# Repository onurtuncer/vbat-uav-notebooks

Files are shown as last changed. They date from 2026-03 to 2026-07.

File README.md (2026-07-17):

# Electric V-BAT-Like Tail-Sitter (EDF) – Conceptual Design Study






**📖 Documentation:** rendered design notebooks are published at
**<https://onurtuncer.github.io/vbat-uav-notebooks/>**

<p align="center">
  <a href="https://onurtuncer.github.io/vbat-uav-notebooks/viewer.html">
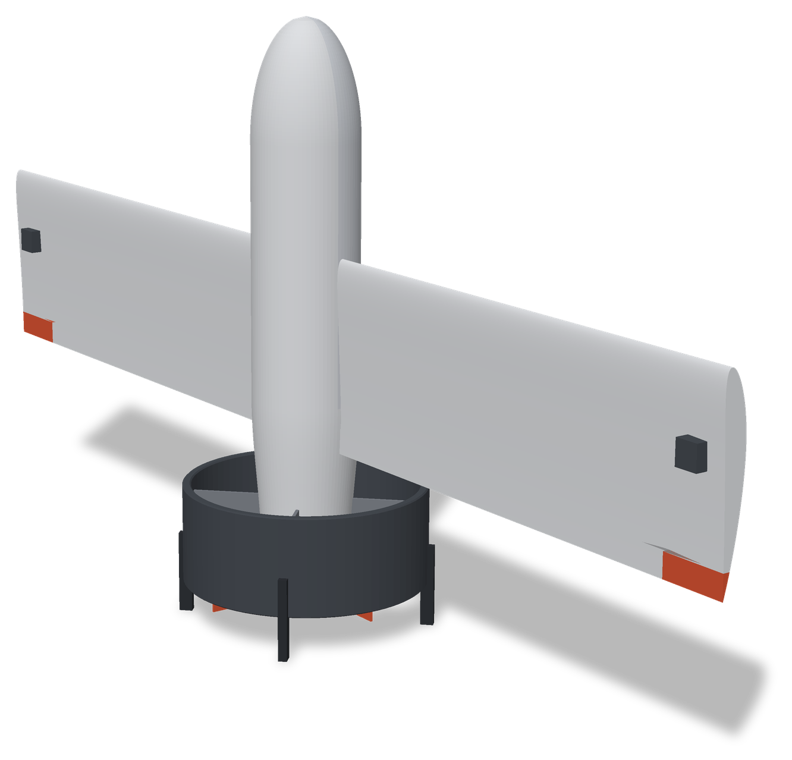
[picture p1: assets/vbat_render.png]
Rendered CAD model of the tail-sitter standing on its landing legs, nose up
    
  </a>
  <br/>
  <em>The current design point, rendered from the CadQuery solid model the
  pipeline exports on every run — click the image for the
  <a href="https://onurtuncer.github.io/vbat-uav-notebooks/viewer.html">interactive 3D viewer</a>
  (orbit, exploded view).
  Regenerate with <code>python scripts/render_readme_cad.py</code> after a design change.</em>
</p>

This repository contains a **first-principles conceptual sizing study** for a **small electric tail-sitter VTOL UAV** inspired by the *very early electric ancestors* of the V-BAT concept.

The focus is **not** on a production UAV, but on:
- architectural feasibility,
- mass / power / energy closure,
- and understanding design trade-offs at the **technology-demonstrator level**.

The code is intentionally simple, transparent, and extensible.

---

## 1. Problem Definition

### Objective
Design a **small electric ducted-fan tail-sitter UAV** capable of:

- **True VTOL** (vertical takeoff and landing)
- **Short forward flight** after transition
- Carrying **0.5 kg of payload**
- Using **electric propulsion only**
- Using **first-order physics models** suitable for early design

This mirrors the *earliest feasibility phase* of tail-sitter concepts before scaling to fuel engines, endurance optimization, or operational payloads.

---

### Design Philosophy
This study intentionally:
- avoids CFD or high-fidelity tools,
- avoids vendor-specific components,
- emphasizes **physics-based intuition**,
- and keeps all assumptions explicit.

The goal is to answer:

> *“Is this architecture feasible at this scale, and where are the dominant penalties?”*

---

## 2. Vehicle Concept (High Level)

- **Configuration:** Tail-sitter VTOL
- **Propulsor:** Electric ducted fan (EDF)
- **Wing:** Fixed wing for forward flight
- **Takeoff / Landing:** Vertical, tail-down
- **Primary regime:** Hover → transition → short cruise

This corresponds to the **electric technology demonstrators** typically built *before* SBIR Phase I funding.

---

## 3. Assumed Mission Profile

The baseline mission used for sizing is:

| Segment | Description |
|---|---|
| Hover | 120 s total (takeoff, landing, margin) |
| Cruise | 1680 s forward flight (~33.6 km at cruise speed) |
| Cruise speed | 20 m/s (~72 km/h) |
| Energy reserve | 20% |

All mission parameters are **editable** in [`config/mission.yaml`](config/mission.yaml).

---

## 4. Payload & Mass Target

- **Payload:** 0.5 kg  
  (sensor + avionics representative of early demonstrators)

Initial mass breakdown assumptions:
- avionics
- structure
- EDF + motor + ESC
- battery
- miscellaneous margin

Mass closure is solved iteratively.

---

## 5. Modeling Approach

### Hover
Hover power is estimated using **momentum (actuator disk) theory**:

$$
P_{ideal} = \frac{T^{3/2}}{\sqrt{2 \rho A}}
$$

with an overall hover efficiency applied to account for:
- duct losses,
- motor/ESC losses,
- non-ideal inflow.

A minimum **thrust-to-weight ratio** is enforced for control margin.

---

### Cruise
Cruise power is estimated using a simple **L/D model**:

$$
P = \frac{W}{(L/D)} \cdot V
$$

This is appropriate for:
- early conceptual sizing,
- rapid trade studies,
- understanding sensitivity to aerodynamic quality.

---

### Battery
Battery mass is computed from:
- total mission energy,
- pack-level specific energy,
- usable fraction (reserve).

No thermal or current limits are enforced at this stage.

---

## 6. Repository Structure

```
config/                  Design inputs (mission, aero, battery, rotor, ... as YAML)
src/conceptual_design/   All physics models (sizing, power, mass closure)
src/conceptual_design/cad/  CadQuery solid-model generators
notebooks/               Design notebooks (import from src/, write to out/)
out/                     Generated design outputs (YAML, STEP/STL, plots)
docs/                    Theory notes (hover, cruise, battery models)
tests/                   Unit tests for the physics modules (pytest)
cfd/                     OpenFOAM cases (vehicle, prop, vanes) + post-processing
printprep/               3D-print preparation scripts
```

### Design rule
- **All physics lives in `.py` files**
- **The notebook only imports and experiments**

This mirrors best practice in research and aerospace R&D codebases.

---

## 7. Requirements

### Python
- Python **3.10+**

### Python packages
Install the package in editable mode with the notebook and CAD extras:

```bash
pip install -e ".[cad,notebooks]"
```

CadQuery (`cad` extra) is only needed for the solid-model notebook
(`vehicle_solid_model.ipynb`); everything else runs on the plain
scientific stack (`pip install -e .`).

### OpenFOAM (optional)
The `Allrun.*` scripts under [`cfd/`](cfd/) run external-aero RANS
analyses of the generated geometry. They require a sourced
**OpenFOAM.com (v2306+)** environment and are independent of the Python
toolchain. See [`cfd/README.md`](cfd/README.md).

## 8. How to Run

Open a terminal in the repository root and launch Jupyter:

```bash
jupyter lab
```

Run the notebooks top-to-bottom **in this order** (each one writes YAML
handoff files to `out/` that the next one reads):

1. `notebooks/vbat_conceptual_design.ipynb` — mission sizing & mass closure
2. `notebooks/wing_design.ipynb` — airfoil selection & wing design
3. `notebooks/control_vane_design.ipynb` — control vane sizing
4. `notebooks/fuselage_design.ipynb` — fuselage layout & drag trade (reads the vane results)
5. `notebooks/vehicle_solid_model.ipynb` — full-vehicle CAD (STEP/STL export)

Adjust parameters in `config/*.yaml` and re-run to explore trade-offs.

### Tests

```bash
pip install -e ".[dev]"
pytest
```

### Versioning & releases

The package version derives from **git tags** via `setuptools-scm`
(`v0.1.0` → `0.1.0`; commits after a tag get a `.devN` suffix — never
edit a version number by hand). Tagging a release freezes the design:

```bash
git tag v0.2.0 && git push --tags
```

CI then re-runs the whole design pipeline and attaches the design
snapshot (design-point YAMLs, STEP/STL geometry, rendered notebooks) to
the [GitHub Release](https://github.com/onurtuncer/vbat-uav-notebooks/releases).
Suggested convention: bump **minor** for a new design point or analysis
capability, **patch** for corrections that do not move the design.

## 9. Intended Extensions

This framework is designed to grow. Natural next steps include:

- wing sizing & stall constraints
- EDF continuous vs burst power limits
- disk loading vs noise trade-offs
- thermal limits (motor & ESC)
- parametric sweeps and Pareto fronts
- hybrid-electric or fuel-based scaling

Each extension should live in new modules

## 10. Scope & Limitations

This study:

❌ is not a flight-ready design

❌ ignores structural stress analysis

❌ ignores control law implementation

❌ ignores certification or safety

It is appropriate for:

- concept feasibility
- academic exploration
- architecture comparison

## 11. Motivation

Tail-sitter VTOL aircraft occupy a unique design space where:

- hover power dominates,
- transition dynamics are critical,
- and endurance scaling is non-trivial.

This repository exists to make those trade-offs explicit and quantitative.

## 12. License

Please see LICENSE file. Open for research and educational use.
(No warranty, no fitness for flight.)

## Author Notes

This project intentionally mirrors how early electric V-BAT-like demonstrators would have been sized before fuel engines, autonomy stacks, or other payloads were introduced.

## 👤 Author

**Prof.Dr. Onur Tuncer**  
Aerospace Engineer, Researcher & C++ Systems Developer  
Email: **onur.tuncer@itu.edu.tr**

<p align="left">
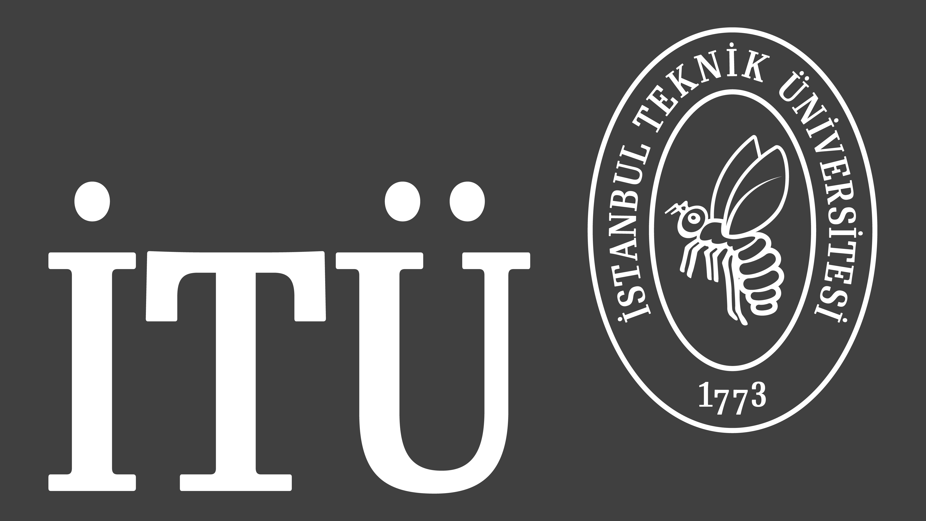
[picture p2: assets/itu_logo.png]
Istanbul Technical University
  
</p>

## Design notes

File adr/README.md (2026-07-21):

# Architecture Decision Records

This folder holds Architecture Decision Records (ADRs) — short documents
capturing an architecturally significant decision, its context, and its
consequences. New ADRs are added when an architectural decision is made;
existing ADRs are never rewritten (a superseding decision gets a new ADR
that marks the old one `Superseded`).

Format: one file per decision, `NNNN-kebab-title.md`, each with
**Status / Context / Decision / Consequences**.

| ADR | Title | Status |
|-----|---|---|
| [0001](0001-one-way-design-pipeline.md) | One-way design pipeline (config → src → notebooks → out → cfd) | Accepted |
| [0002](0002-all-physics-in-src-no-magic-numbers.md) | All physics in `src/`; no magic numbers in Python | Accepted |
| [0003](0003-cots-edf-derived-disk-loading.md) | COTS 195 mm EDF; disk loading derived, not configured | Accepted |
| [0004](0004-dual-roll-control-vanes-and-ailerons.md) | Dual roll control: jet vanes (hover) + ailerons (cruise) | Accepted |
| [0005](0005-mass-fraction-carve-out-with-traceability.md) | Mass-fraction carve-out with traceability and a guard | Accepted |
| [0006](0006-tag-driven-versioning-and-ci-tiers.md) | Tag-driven versioning and tiered CI | Accepted |
| [0007](0007-vibration-isolation.md) | Soft-mount the FC/IMU and payload against EDF imbalance | Accepted |
| [0008](0008-segmented-fdm-construction.md) | Segmented-FDM construction as the baseline airframe | Amended by 0010 |
| [0009](0009-thermal-paths-as-structure.md) | Thermal paths as structure (ESC cold-plate + vented battery bay) | Accepted |
| [0010](0010-semi-monocoque-clamshell.md) | Semi-monocoque clamshell fuselage (external review) | Accepted |
| [0011](0011-px4-flight-validation-before-custom-fc.md) | Fly on PX4 + COTS Pixhawk before a custom flight controller | Accepted |
| [0012](0012-post-freeze-as-selected-resolve.md) | Post-freeze as-selected re-solve as new downstream notebooks | Accepted |
| [0013](0013-thin-notebooks-code-in-src.md) | Thin notebooks: physics/plots/reports code lives in src | Accepted |
| [0014](0014-battery-pack-transient-thermal-check.md) | Battery pack mission-transient thermal check | Accepted |
| [0015](0015-naca-4412-airfoil-reselection.md) | Airfoil re-selection: NACA 2412 → NACA 4412 | Accepted |
| [0016](0016-aeolion-geometry-handoff.md) | Versioned JSON plus STEP for the Aeolion handoff | Accepted |
| [0017](0017-prop-blade-clark-y-section-and-rotation-sense.md) | Propeller blade section (Clark Y) and rotation sense | Accepted |
| [0018](0018-aeolion-handoff-own-notebook.md) | Aeolion handoff as its own pipeline notebook stage | Accepted |

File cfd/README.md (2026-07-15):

# CFD Cases (OpenFOAM)

RANS (simpleFoam, k-omega SST) cases characterizing the V-BAT tail-sitter,
using geometry and reference quantities produced by the notebooks
(`out/cad/`, `out/fuselage.yaml`, `out/control_vanes.yaml`,
`config/mission.yaml`). Tested against OpenFOAM.com v2306+.

| Directory | Purpose |
|---|---|
| `vehicle/` | Full-vehicle external aero: mesh from `out/cad/stl/vbat_fused.stl`, single-AoA runs, and AoA polar sweeps |
| `prop/` | Ducted-fan propulsion map via actuator disk (parametric duct + centerbody geometry, thrust x velocity sweep) |
| `vanes/` | Control-vane characterization: flat-plate vane in the duct jet, deflection sweep |
| `postprocess/` | Exporters from `postProcessing/` force histories to DAVE-ML (`foam2dml.py` for the vehicle polar, `foam2dml_prop.py` for prop/vane sweeps) |

## Run order

```bash
# Full-vehicle aero polar (requires repo STL/STEP under out/cad/)
cd vehicle
./Allrun.mesh                      # geometry -> snappyHexMesh -> checkMesh
./Allrun.case -a 0 -V 20 -n 8 -s   # single AoA, or:
./Allrun.polar -n 8 -V 20 -- -4 -2 0 2 4 6 8 10 12
python3 ../postprocess/foam2dml.py --polar-dir polar --out vbat_aero_cfd.dml --plot

# Propulsion map (duct/hub dims read from out/fuselage.yaml via make_geom.py)
cd prop
./Allrun.prop -n 8
python3 ../postprocess/foam2dml_prop.py --prop-dir sweep

# Vane sweep
cd vanes
./Allrun.vanes -n 8
python3 ../postprocess/foam2dml_prop.py --vane-dir sweep
```

Run artifacts (meshes, `log/`, `processor*/`, `postProcessing/`, sweep
directories) are generated in place and gitignored; only the Allrun
scripts, `system/` dictionaries, and Python tooling are tracked.

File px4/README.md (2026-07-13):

# px4/ — PX4 flight-stack configuration (ADR-0011)

Pipeline consumer, downstream of `out/` — the same role `cfd/` plays:

```
config/*.yaml -> src/ -> notebooks/ -> out/ -> px4/   (this directory)
                                        |
                                        v
                              cfd/ sweep results
                                        |
                                        v
                     out/daveml/*.dml  (generated, AIAA S-119)
                                        |
                                        v
                    Aetherion 6-DoF plant (separate repo)
                                        |
                          simulator-MAVLink lockstep (TCP 4560)
                                        |
                                        v
                                   PX4 SITL
```

The SITL physics plant is **Aetherion** (github.com/onurtuncer/Aetherion)
consuming DAVE-ML models generated from this repo's CFD results — the
built-in Gazebo aero is not trusted for this vehicle (no jet wash, no
post-stall, no power-on effects; see ADR-0011). The DAVE-ML contract
lives in [sitl/daveml_spec.md](sitl/daveml_spec.md).

Everything numeric in here is **copied from `config/` or `out/`
handoffs** and carries a provenance comment naming the source (the
`Allrun.case` discipline). An intentional design change must update
these values in the same commit. A generator script from `out/*.yaml`
is the planned follow-up once the file set stabilises.

Design point (ADR-0003 prop-in-duct amendment, 2026-07-12): MTOW
2.302 kg, hover ~652 W / 29.4 N (1.3 T/W), 6S 3.50 Ah, cruise 20 m/s.

## Layout

| Path | What it is |
|---|---|
| `airframes/22100_vbat_tailsitter` | Hardware airframe file (custom start script for the PX4 ROMFS, `init.d/airframes` style). Source of truth for all tunable params. |
| `sitl/daveml_spec.md` | Contract for the CFD-derived DAVE-ML model set (`out/daveml/*.dml`) consumed by Aetherion — grids, frames, check-cases, validation gates. |
| `sitl/airframes/4801_gz_vbat_tailsitter` | SITL (Gazebo `gz`) airframe file, `init.d-posix` style. Param values are kept in sync with the hardware file by hand. |
| `sitl/models/vbat_tailsitter/` | Gazebo model (`model.sdf` + `model.config`) — **integration smoke checks and visualisation only**, not a trusted plant. Inertia from `out/mass_properties.yaml`, geometry from `out/fuselage.yaml` / `out/control_vanes.yaml`. |

The PX4 lockstep bridge and sensor models live in the Aetherion
repository; this repo only produces the `.dml` inputs and the PX4
parameter set.

## Vehicle → PX4 mapping

- **Airframe type:** VTOL Tailsitter (`CA_AIRFRAME = 4`, `VT_TYPE = 0`),
  dynamic control allocation (PX4 ≥ v1.14).
- **Motor:** single ducted 3-blade prop, `CA_ROTOR_COUNT = 1`, thrust along body +x
  (out the nose, FRD).
- **Jet vanes:** four custom control surfaces (CS0–CS3 = T/B/L/R). Their
  roll/pitch/yaw torque entries transcribe the mixing matrix in
  `out/control_vanes.yaml` (rows T,B,L,R × cols pitch,yaw,roll).
- **Ailerons:** CS4/CS5 as left/right aileron — the cruise-phase roll
  effector (ADR-0004); jet vanes remain available as roll backup.
- **Outputs:** 1 ESC (DShot preferred — RPM telemetry feeds the dynamic
  notch filter) + 6 servos.

## Known limitations / open work

1. **Param names are drafted against PX4 v1.15 docs and not yet
   validated against a pinned release.** Validate before first SITL run;
   then add cross-checks to `tests/test_design_outputs.py`.
2. **The trusted SITL plant does not exist yet.** Its pieces are named
   work items (ADR-0011): the parametric CFD sweep runner and the
   DAVE-ML generator in this repo, the PX4 lockstep bridge + sensor
   models in Aetherion. The Gazebo model remains usable for PX4-side
   plumbing checks (actuator mapping, mode logic, parameter sanity) but
   its vane aero blocks are physically meaningless placeholders — the
   plugins see the freestream, not the rotor jet — so no flight-dynamics
   conclusion may be drawn from it.
3. **Vane effectiveness ∝ thrust** is not modelled by PX4's allocator —
   expect apparent gain variation through transition; tune with the
   ailerons carrying cruise roll as designed.
4. Servo directions/signs must be verified on the bench against the
   FRD axis convention before flight — the matrix here fixes relative
   signs only.

## Usage

**SITL against Aetherion (the trusted path, once the bridge exists):**
build the Aetherion PX4 bridge pointing at `out/daveml/`, start PX4 with
no built-in simulator (`make px4_sitl none_vbat_tailsitter` — external
sim connects on TCP 4560 in lockstep), then launch the bridge. Exact
invocation is defined by the bridge in the Aetherion repo.

**Gazebo smoke run** (PX4-side plumbing checks only — not flight
dynamics; Linux, PX4-Autopilot checkout, Gazebo Harmonic):

```sh
# make the model and airframe visible to the PX4 build
export GZ_SIM_RESOURCE_PATH=$GZ_SIM_RESOURCE_PATH:/path/to/vbat-uav-notebooks/px4/sitl/models
cp px4/sitl/airframes/4801_gz_vbat_tailsitter \
   PX4-Autopilot/ROMFS/px4fmu_common/init.d-posix/airframes/
# add it to that directory's CMakeLists.txt, then:
make px4_sitl gz_vbat_tailsitter
```

**Hardware:** copy `airframes/22100_vbat_tailsitter` into
`ROMFS/px4fmu_common/init.d/airframes/` of a PX4 source build (register
it in the CMakeLists), or replay the same `param set-default` lines as a
QGroundControl parameter import after selecting a generic VTOL
tailsitter airframe.

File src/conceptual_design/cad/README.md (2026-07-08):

# CAD Assets – VBAT Conceptual Design

This directory contains all CAD geometry related to the electric
tail-sitter (VBAT-style) UAV conceptual design.

Geometry is generated programmatically using **CadQuery**
(built on OpenCascade / OCCT).

---

## Philosophy

All primary geometry should be:

- Parametric
- Reproducible
- Script-generated when possible
- Version-controlled at the source level

The CAD models are treated as **derived artifacts** from the Python
conceptual design codebase.

---

## Directory Structure

This package contains the geometry **generators**:

cad/
├─ wing_profile.py      # NACA sections (math from airfoil_selection.py)
├─ fuselage_body.py     # body of revolution (meridian from fuselage_design.py)
├─ vehicle_assembly.py  # full vehicle: fuselage, wing, duct, vanes, legs
└─ README.md

Generated artifacts are **derived outputs** and live under `out/` (gitignored):

out/cad/
├─ step/ # STEP solids for CAD exchange (assembly + fused)
└─ stl/  # Mesh exports for visualization or 3D printing

## Axis Convention (Aetherion-compatible)

Body frame **FRD**: x forward (out the nose), y right, z down.
Origin at the nose tip; the EDF exhaust points in -x.
World frame is NED.

## Units

- Public function arguments and all `out/*.yaml` handoffs: **meters (m)**
- OCCT geometry and STEP/STL exports: **millimetres (mm)** (CAD convention);
  scaling happens inside the modules.

---

## Generation Workflow

CAD geometry is generated from Python using:

Typical workflow:

1. Adjust parameters in `config/*.yaml`.
2. Re-run the upstream notebooks (sizing -> airfoil -> vanes -> fuselage).
3. Run `notebooks/vehicle_solid_model.ipynb` to regenerate
   `out/cad/step/` and `out/cad/stl/`.

Example (full vehicle from the YAML handoffs):

```python
import yaml
from conceptual_design.cad.vehicle_assembly import build_vehicle, export_vehicle

fus   = yaml.safe_load(open("out/fuselage.yaml"))
vanes = yaml.safe_load(open("out/control_vanes.yaml"))
asm, fused = build_vehicle(fus, vanes, b_wing_m=1.002,
                           chord_wing_m=0.167, wing_designation="NACA 2412")
export_vehicle(asm, fused, "out/cad")
```

## Planned Geometry Modules

- Wing (lofted root–tip sections)
- Spar cutouts
- Rib generation
- Fuselage parametric body
- Duct / fan housing
- Mounting structures

## Long-Term Goal

CAD is tightly coupled to the conceptual design:

- Mission → mass → wing loading → chord/span → geometry

Geometry should be derivable from YAML configuration

This ensures:

-Design traceability
-Repeatability
-Parametric trade studies

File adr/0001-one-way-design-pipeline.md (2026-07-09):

# 1. One-way design pipeline (config → src → notebooks → out → cfd)

Status: Accepted

## Context

A conceptual design study couples many disciplines (mission sizing,
aerodynamics, structures, CAD, CFD, electrical). Left unstructured, inputs,
physics, and orchestration bleed into each other: constants get hard-coded in
notebooks, one notebook reaches into another's internals, and reproducing a
design point becomes guesswork. We need a data-flow discipline that makes the
design point reconstructible and every artifact traceable to its inputs.

## Decision

Data flows one way through five stages:

```
config/*.yaml  ->  src/conceptual_design/  ->  notebooks/  ->  out/  ->  cfd/
(inputs)           (ALL physics)               (orchestrate)   (handoffs)  (consumers)
```

- `config/*.yaml` holds every input parameter.
- `src/` holds all physics as importable modules.
- Notebooks only set parameters, call modules, interpret results, and write
  YAML/CSV **handoffs** to `out/`.
- Each notebook reads only the `out/` handoffs of the notebooks before it and
  re-runs `run_sizing_loop` from `config/` to reconstruct the same design
  point. Notebook execution order is therefore load-bearing.
- CFD and other consumers read `out/` but never feed back into it.

## Consequences

- The design point is reconstructible from `config/` alone; `out/` is a
  cache, regenerated by re-running the notebooks in order.
- Changing the sizing API means updating every notebook's `run_sizing_loop`
  call site (NB2–NB8) — a known, enumerated cost.
- Cross-notebook coupling is explicit and append-only (via `out/` files),
  which is what lets CI regenerate and regression-check the whole chain.
- No backward edges: a downstream discovery (e.g. a CG shift found in
  `mass_properties`) is fed back by changing `config/`/`src/` and re-running,
  not by editing an upstream `out/` file in place.

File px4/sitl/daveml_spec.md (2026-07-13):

# DAVE-ML model database spec (draft, ADR-0011)

Contract between this repo's CFD results and the Aetherion 6-DoF plant
used for PX4 SITL. Producer: a generator script in this repo (follow-up
work item) writing `out/daveml/*.dml` from CFD sweep results + existing
`out/` handoffs. Consumer: Aetherion's `Serialization/DAVEML` readers
(`DAVEMLAeroModel` via the generic `evaluateRaw` map interface,
`LoadInertiaFromDAVEML`, a prop-style wrapper).

Conformance: **DAVE-ML 2.0 (AIAA S-119)**, gridded tables + MathML,
embedded check-cases mandatory (Aetherion's F-16 files are the style
reference). Units: **SI native** (m, m/s, N, N·m, deg for angles,
matching the F-16 file convention of degrees for aero angles).
NOTE: Aetherion's `getValueSI` assumes imperial native units (slug, ft);
verify its readers pass SI-native units through unchanged — flagged as
an Aetherion-side check.

## Frames, references, provenance

- Body **FRD**, x out the nose (project-wide convention). Moments about
  the CG; forces/moments and their coefficient forms use the same signs
  as the F-16 reference set (`cx` +fwd, `cz` +down, `cm` +nose-up, …).
- Reference quantities pinned to `cfd/vehicle/Allrun.case` (and the
  regression pins in `tests/test_design_outputs.py`):
  `S_ref = 0.18925 m²`, `c_ref = 0.17760 m` (MAC = chord, rectangular
  wing), `b_ref = 1.0655 m`, moment centre `(-0.23841, 0, 0)` = CG.
- Every file carries the standard AUTO-GENERATED provenance header
  (source case, mesh/solver settings hash, generation date) and is
  re-generated — never hand-edited — when the design point moves.

## The hover-normalisation split (structural decision)

At hover `q_∞ → 0`, so `C = F/(q_∞ S)` is singular exactly where a
tailsitter lives. The database is therefore split:

| File | Form | Valid regime |
|---|---|---|
| `vbat_aero.dml` | coefficients (power-off airframe) | V ≥ ~5 m/s |
| `vbat_prop.dml` | **dimensional** N / N·m vs throttle state | all speeds |
| `vbat_vanes.dml` | **dimensional** N / N·m vs deflection + jet state | all speeds |
| `vbat_inertia.dml` | constants | — |

Total loads = airframe coefficients (faded in with airspeed) +
prop/duct + vane increments. Aetherion composes the superposition; the
fade law is defined here (breakpointed on airspeed), not hardcoded there.

## vbat_aero.dml — power-off airframe

Inputs: `alpha` [deg], `beta` [deg], `vt` [m/s], `p`,`q`,`r` [rad/s],
`da_l`,`da_r` [deg] (aileron deflections).
Outputs: `cx cy cz cl cm cn`.

Draft breakpoint grid (transition corridor gets the density):

- `alpha`: −180…180; 2.5° steps in [−10, +30], 5° in [30, 90], 15°
  beyond (tail-sitter passes through 90° — the post-stall band is the
  point of doing this at all)
- `beta`: 0, ±5, ±10, ±20 (symmetry exploited in generation)
- `vt`: 5, 10, 16, 20, 26 m/s (Re sensitivity check decides whether
  the vt axis survives or collapses to one Re)
- aileron: 0, ±10, ±20° (increments; rate derivatives `p,q,r` are NOT
  CFD-derived initially — first fill from analytic/DATCOM estimates,
  flagged `estimated` in the varDef description, replaced if forced
  oscillation or system-ID data arrives)

## vbat_prop.dml — EDF + duct, power-on

Inputs: `throttle` [0–1] (or `rpm`), `vt` [m/s], `alpha` [deg].
Outputs: `fx_N fy_N fz_N mx_Nm my_Nm mz_Nm` **plus `q_jet_Pa`** (feeds
the vane model — the F-16 prop file has no such coupling; this one must).
Must capture duct normal force and pitching moment at incidence
(dominant tailsitter transition effect) — this is the actuator-disk CFD
sweep, power-on minus power-off.

Draft grid: throttle {idle, cruise ≈ 0.15, hover 0.61, max 1.0} ×
vt {0, 5, 10, 16, 20, 26} × alpha {0, 15, 30, 60, 90}.
Static check-cases: hover 30.3 N at throttle 0.61; `T_max_N` 50 at 1.0
(config/rotor.yaml); `q_jet` 780.3 Pa at hover (out/control_vanes.yaml).

## vbat_vanes.dml — jet vane increments

Inputs: `dv_t dv_b dv_l dv_r` [deg, ±20 hard stop], `q_jet_Pa` (from the
prop model), `vt`, `alpha`.
Outputs: incremental `fx_N … mz_Nm` about the CG.

Draft grid: deflection −20…+20 in 5° steps (one vane swept, others
zero; cross-coupling spot-checked), q_jet {cruise, 0.5·hover, hover,
max}. First-issue tables may come from the analytic model in
`src/conceptual_design` (provenance-flagged), replaced by CFD
(resolved-vane or momentum-source runs) sweep by sweep — the .dml
interface stays fixed while fidelity improves underneath.
Check-case: 10° single vane at hover q_jet → 0.719 N
(out/control_vanes.yaml) for the analytic issue; re-pinned when CFD
replaces it.

## vbat_inertia.dml

Straight transcription of `out/mass_properties.yaml`: mass 2.37626 kg,
Ixx 0.022453, Iyy 0.041776, Izz 0.054148 kg·m² (products zero), CG
(-0.23841, 0, 0). Battery-tray CG travel (±0.025 m) exposed as the one
input variable, mirroring the F-16 file's `CG_PCT_MAC` pattern.

## Validation gates (Aetherion side)

1. S-119 embedded check-cases pass in Aetherion's Catch2 suite.
2. Static hover trim: thrust = weight at throttle ≈ 0.61, vanes ≈ 0.
3. Cruise trim at 20 m/s reproduces CL ≈ 0.50 and L/D consistent with
   `out/airfoil.yaml` (13.2 wing-only, less airframe drag).
4. Vane authority at hover reproduces the `ddot_*` design values of
   `out/control_vanes.yaml` before any PX4 gain tuning is attempted.

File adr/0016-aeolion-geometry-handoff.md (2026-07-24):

# ADR-0016: Schema-pinned parametric JSON for the Aeolion geometry handoff

Status: Accepted (2026-07-19; supersedes the earlier ad-hoc JSON draft)

## Context

Aeolion (companion VLM/BEMT repo) closes an adjoint optimization loop
over the VBAT geometry. It needs a differentiable, fixed-topology
parametric description — not the watertight STEP solid, whose booleans
and tessellation are nondifferentiable. The Aeolion side pinned the
contract as a JSON Schema (2020-12, `additionalProperties: false`).

## Decision

- The contract is `schemas/vbat-aeolion-geometry-handoff.schema.json`
  (schema_version **1.0.0**), stored verbatim in this repo and
  validated by `tests/test_aeolion_handoff.py` (jsonschema, dev extra).
- NB8 (`vehicle_solid_model`) exports `out/cad/aeolion_geometry.json`
  beside the STEP files (same execution ⇒ same design point), built by
  `src/conceptual_design/aeolion_handoff.py`.
- **Frame/units**: `aetherion_body_frd`, metres, degrees — identical to
  the repo axis convention, so there is no transform seam to
  differentiate through.
- **Fixed design-vector structure**: station count, CST order, BEMT
  station count, and mesh topology come from `config/aeolion.yaml` and
  are structural constants of the optimization, not design variables.
  Changing them is an outer-loop remeshing event (deliberate commit).
- **Airfoil sections are Kulfan CST fits** (class function
  x^0.5·(1−x)^1.0, least squares) of the NB2-selected section. The
  schema has no trailing-edge-thickness term, so each surface is fitted
  after removing the linear TE ramp — the handoff carries the sharp-TE
  aerodynamic equivalent (what a VLM camber surface consumes). Fit RMS
  is test-guarded at < 1e-3 c.
- **BEMT blade stations sample the same chord/twist law as the CAD
  rotor** (`prop_geometry.PropGeometry`, moved out of `cad/` so it
  imports without CadQuery): r/R from the hub collar to the tip, exact
  constant-geometric-pitch twist, `reference_rpm` from the NB5 hover
  1/rev. One law, three consumers (CAD, BEMT, vibration-forcing).
- **Controls**: the aileron and the four jet vanes are emitted. Vane
  entries reuse the schema's control-surface shape for the duct jet:
  eta is the duct-exit radius fraction (hub collar → duct wall), the
  hinge axes are the radial vane directions (CAD angle convention:
  about +x, 0° = +z), and `chord_fraction: 1.0` marks the all-moving
  plate rotating about its `hinge_xc` line. The vane CFD → DAVE-ML
  path still characterizes the jet-wash aerodynamics; carrying the
  geometry here lets Aeolion model the jet directly.
- **Duct block (schema 1.8.0, 2026-07-24)**: the EDF shroud rides in
  the contract explicitly — a new top-level `duct` block with
  `inner_diameter` / `outer_diameter` / `chord` and
  `placement.center`, the SAME parameterisation the CAD duct solid is
  built from (`out/fuselage.yaml` `D_duct_inner_m` / `D_duct_outer_m`
  / `duct_chord_m` and the layout duct station): an annulus of
  revolution about the body x-axis, mid-chord centre at x = −station
  (same convention as `body`), inlet face forward at
  `center.x + chord/2`. Before this the duct existed in the contract
  only by implication — the vane entries' eta is measured on the
  duct-EXIT radius and BEMT models a prop-in-duct, yet no duct
  geometry or position was stated anywhere, so a duct-aware consumer
  had nothing to place against `body` (and the duct legitimately
  overhangs the tail base, so guessing from the body extent gets it
  wrong). The bore carries the rotor tip clearance — new exporter
  guard `rotor_D < D_duct_inner < D_duct_outer`, plus exactly one
  `duct` item required in the fuselage layout. **Required from 1.8.0
  onward**, same version-conditional `if`/`then` discipline as
  `planform.placement` and `moment_reference_point`; 1.0.0–1.7.0
  documents remain structurally valid without it.
- **Moment reference point (schema 1.6.0, 2026-07-21, from an Aeolion
  solver report)**: a new top-level `moment_reference_point` {x, y,
  z} carries the vehicle CG, in the SAME body-frame convention and
  from the SAME source (`out/fuselage.yaml` `x_CG_m`) as
  `cfd/vehicle/Allrun.case`'s `CofR` — so VLM/BEMT moments computed
  from this contract stay directly comparable to the project's CFD
  force/moment coefficients, not an arbitrary second reference.
  Without it, Cm/Cl/Cn have no stated centre and default to the
  coordinate-system origin — not physically meaningful for a body
  whose CG sits well aft of the nose. **Required from 1.6.0 onward**,
  same discipline as `planform.placement`: a version-conditional
  `if`/`then` (`schema_version` not in the pre-1.6.0 list ⇒
  `moment_reference_point` required at the document root), so
  1.0.0–1.5.0 documents remain structurally valid without it. New
  exporter guard mirrors the placement guard: `0 < x_CG_m < L_fus_m`.
- **Wing/body placement (schema 1.5.0, 2026-07-20, from an Aeolion
  solver-side bug report)**: `planform` gained a `placement.
  root_leading_edge` anchor {x, y, z} in the same body-frame
  convention `body` already uses (x = -station, 0 at the nose tip).
  Before this the planform and the body profile each implicitly
  started at the reference-frame origin, so a consumer with no other
  convention to fall back on placed the wing root at the fuselage
  nose — 22 of 384 wing control points landed inside the body of
  revolution in Aeolion's report, a boundary condition with no
  physical meaning. The anchor is `[-x_wing_LE_m, 0, 0]`: the wing
  chord datum sits on the fuselage centerline by construction (a
  through-fuselage wing on the ADR-0008 carry-through spar), not an
  incidental default. **Required from 1.5.0 onward** — unlike every
  earlier addition, this field is NOT optional for its own version,
  because the unsafe fallback (assume the origin) is exactly the bug
  being fixed; the schema enforces this with a version-conditional
  `if`/`then` (`schema_version` not in the pre-1.5.0 list ⇒
  `planform.placement` required) rather than a prose promise, so
  1.0.0–1.4.0 documents that never carried it remain structurally
  valid while every 1.5.0+ document is held to the anchor. The
  exporter also guards `0 < x_wing_LE_m < L_fus_m` so a future design
  change can't silently regress the wing outside the fuselage again.
  The natural follow-on — trimming the wing planform/lattice at the
  fuselage surface so the root load transfers to the body — is left
  to Aeolion's side now that placement exists; it needs the `body`
  radius law (already in the contract since 1.2.0) evaluated at the
  root LE station, not a new VBAT field.
- **Deflection range (schema 1.4.0, 2026-07-20)**: every
  `control_surfaces` entry carries `deflection_limits_deg` — the
  symmetric mechanical range about `hinge_axis` (`±delta_max_deg` from
  `out/aileron.yaml` / `out/control_vanes.yaml`), so a CFD/VLM
  deflection sweep never asks for an angle the physical actuator/plate
  cannot reach. Vane entries additionally carry
  `deflection_soft_limit_deg` (the flat-plate stall onset,
  `delta_stall_deg`) — informational, not a hard bound, since sweeping
  past it is a legitimate (if off-design) query.
- **Blade count (schema 1.3.0, 2026-07-20, missing field caught in
  review)**: `propulsion_bemt.n_blades` (from the same
  `prop_geometry.PropGeometry` the blade stations sample). BEMT
  solidity and thrust are per-blade quantities scaled by blade count —
  `blade_stations` alone describes one blade's chord/twist law, not
  the rotor, so the count was a load-bearing gap, not an
  optional refinement.
- **Body block (schema 1.2.0, 2026-07-19)**: the fuselage rides in the
  contract as a body of revolution — `body.stations` of {x, radius}
  sampled from the same 3-segment meridian the CAD revolve is built
  from (`fuselage_design.fuselage_radius`: elliptical nose, cylinder,
  tail cone to the hub radius), cosine-spaced nose → tail at a fixed
  count (`n_body_stations`, config/aeolion.yaml), body x = −station
  (0 at the nose tip, negative aft, consistent with
  `aetherion_body_frd`). Optional in the schema (1.0.0/1.1.0 documents
  stay valid); never bound to a lifting lattice — intended for
  slender-body/Munk trim corrections and duct-jet context. One
  meridian law, two consumers (CAD revolve, handoff).
- **Surface binding (schema 1.1.0, 2026-07-19, from the Aeolion-side
  review)**: control-surface entries carry an explicit `surface` field
  — `wing` (eta = semispan fraction of the planform) or `duct_jet` (an
  all-moving plate in the jet, eta = duct-exit radius fraction, never
  bound to a lifting-surface lattice). The field is optional so 1.0.0
  documents stay valid; when absent the binding convention is by
  `name`: `aileron`/`rudder` → `wing`, `vane` → `duct_jet`. The
  exporter always emits it. Frame conversion remains the consumer's
  explicit job at ingest (the contract states `aetherion_body_frd`
  once; a z-up VLM flips x and z — a proper rotation about y).
- **`design_id`** is `sha256:<hex>` over the canonical JSON of every
  other field: byte-stable when the design point is unchanged (clean
  regression diffs), guaranteed to move when any parameter moves —
  the adjoint-loop traceability key.

## Rationale

VLM needs a mean lifting lattice; passing span, per-station chord /
twist / sweep / dihedral, and CST sections preserves design intent and
keeps every quantity on a differentiable path. A CppAD implementation
can template geometry → residual → solve → objective on the scalar
type; JSON parsing stays outside the tape and supplies values, while
the fixed array lengths guarantee a constant tape structure.

STEP remains the exact CAD/traceability artifact, but because the
schema forbids additional properties, the STEP linkage is by
construction (same NB8 run, same `out/cad/` directory) rather than by
a field inside the JSON.

## Consequences

- Any change of field meaning requires a schema-version bump on the
  Aeolion side first; this repo follows the pinned schema file.
- The document intentionally repeats identical chord/CST data at every
  station today (rectangular untwisted wing) — that redundancy IS the
  contract for future twist/taper design variables.
- Design changes show up as a new `design_id`; CI's byte-diff of
  `out/cad/aeolion_geometry.json` doubles as a design-regression pin.

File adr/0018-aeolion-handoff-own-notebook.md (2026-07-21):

# ADR-0018: Aeolion handoff as its own pipeline notebook stage

Date: 2026-07-22
Status: Accepted

## Context

`build_aeolion_geometry`/`export_aeolion_geometry` (ADR-0016) were
called from a tail cell of `vehicle_solid_model` (NB8) because that's
where the CAD assembly and the parametric prop rotor were already
being built, and the ADR-0016 rationale explicitly framed the JSON as
sitting "beside the existing assembly and fused STEP files."

Since then the contract has grown: six schema revisions in three days
(1.0.0 → 1.7.0, ADR-0016/0017), a real design decision of its own
(the Clark Y blade section, ADR-0017), and a numerically-derived
physical fact (rotation sense) — enough surface area that it no longer
reads as an afterthought at the end of the CAD notebook.

It's also, on inspection, not actually coupled to CAD at all:
`build_aeolion_geometry`'s every input — wing span/chord from the
sizing result, `out/airfoil.yaml`, `out/control_vanes.yaml`,
`out/aileron.yaml`, `out/vibration.yaml`, `out/fuselage.yaml`,
`config/prop_geometry.yaml`, `config/airfoils/clarky.dat`,
`config/aeolion.yaml` — comes from `config/` or an upstream `out/*.yaml`
handoff, never from the CAD solid or its STEP/STL exports. Both
`aeolion_handoff.py` and `prop_geometry.py` are already, deliberately,
CadQuery-free (their own docstrings say so, "so the handoff and its
tests run in environments without OCCT").

## Decision

Split the Aeolion export into its own notebook, **`aeolion_handoff`**,
inserted as **NB9** (immediately after `vehicle_solid_model`,
renumbering `mass_properties` → NB10 through `design_summary` → NB16).
It uses the same thin-notebook pattern as every post-ADR-0013 notebook
(`design_point.solve_design_point` as the sizing-loop call site,
`design_point.load_handoff` for the upstream `out/*.yaml` reads) rather
than NB8's special inline `run_sizing_loop` block.

`vehicle_solid_model` keeps building the parametric prop rotor solid
(`PropGeometry`/`ClarkYSection` are still needed there, for the CAD
loft) and exporting STEP/STL; it just drops the trailing Aeolion-export
cell. `out/cad/aeolion_geometry.json` keeps its existing path — the
"beside the STEP files" convention is about file layout, not about
which notebook writes it.

Because NB9 has no CadQuery dependency, it can regenerate
`out/cad/aeolion_geometry.json` **even when NB8 is skipped** (no OCP
wheel, local Python 3.14 venv) — a genuine practical improvement, the
same property `wiring_diagram` (NB11) already has.

## Consequences

- Pipeline is now sixteen notebooks. `CLAUDE.md`,
  `.github/workflows/design-pipeline.yml`'s `NOTEBOOK_ORDER`,
  `.github/workflows/release.yml`'s minimal notebook list, and
  `.claude/skills/run-vbat-uav-notebooks/driver.py`'s `NOTEBOOKS` list
  all updated in the same commit.
- `out/cad/aeolion_geometry.json`'s content is unaffected by the
  split — same inputs, same code, same `design_id` — verified by
  running the full pipeline and diffing against the pre-split file.
- Future Aeolion-side schema/BEMT work (further fields, another
  section decision, etc.) has a natural home that doesn't require
  touching the CAD notebook or a CadQuery-capable environment to
  iterate on.

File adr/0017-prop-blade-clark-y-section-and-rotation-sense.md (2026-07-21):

# ADR-0017: Propeller blade section (Clark Y) and rotation sense

Date: 2026-07-21
Status: Accepted

## Context

Two related gaps surfaced from Aeolion-side BEMT integration work on the
ADR-0016 geometry handoff:

1. `propulsion_bemt.blade_stations` carried only `r_over_R`/`chord`/`twist`
   — no 2D section shape at all. The CAD rotor (`cad/prop_rotor.py`) built
   its blade from an ad-hoc parametric taper (`camber_M`/`camber_P`/
   `tc_root`/`tc_tip` in `config/prop_geometry.yaml`, described only as
   "NACA 4-digit, thickness tapering root -> tip") — a proprietary shape
   invented for this project, with no published 2D polar data a BEMT
   solver could use. As the user put it: "Most researchers start with a
   well-documented low-Re airfoil rather than a proprietary propeller
   section."
2. `propulsion_bemt` carried no rotation sense at all. Thrust direction,
   torque reaction, and swirl sign in a BEMT/VLM solve all depend on it,
   and there is no safe default (the two options are ~180° apart in
   blade-element angle of attack, not a small ambiguity).

## Decision

### Blade section: Clark Y

Three well-documented low-Re candidates were on the table, each with a
real trade-off:

| section | character | fit for this rotor |
|---|---|---|
| Selig S1223 | extreme camber, very high lift, optimized for one design point (max static thrust) | poor: this prop drives BOTH hover and forward flight as the same blade, not a single hover operating point |
| Eppler E387 | general-purpose low-Re section, extensively wind-tunnel validated (UIUC) | fine, but a wing-proven section more than a propeller-proven one |
| **Clark Y** | robust, moderate camber, the classical propeller section with the deepest track record in propeller BEMT/momentum-theory validation literature | **best fit**: well-behaved across the wide AoA/advance-ratio range a multi-regime (hover + cruise) rotor actually sees, and maximizes comparability with existing validated propeller theory |

**Clark Y wins.** Coordinates are the digitized UIUC Airfoil Coordinates
Database file (`config/airfoils/clarky.dat`, verbatim, Lednicer format,
61+61 points; provenance in the `.dat.source` sidecar — fetched twice
independently, byte-identical, and sanity-checked against the published
characteristics: max t/c 11.71% at x/c=0.28 vs the commonly cited 11.7%,
max camber 3.43% at x/c=0.42 vs the commonly cited ~3.4–3.55%).

The reference section is decomposed into a camber line
`yc = (yu+yl)/2` and a half-thickness distribution `yt = (yu-yl)/2`
(`prop_geometry.ClarkYSection`/`_scaled_clarky_surfaces`), then
thickness-scaled per blade station by `tc_target / tc_ref` — the
standard way a published section is adapted to a locally different
thickness along a span while preserving its camber-line identity (the
same decomposition the wing's own NACA formula already keeps separate).
`config/prop_geometry.yaml`'s `tc_root`/`tc_tip` keys are repurposed as
these scaling targets; `camber_M`/`camber_P` are removed (Clark Y's
camber is now fixed by real data, not a free parameter). One section
law, two consumers: `cad/prop_rotor.py`'s loft and the Aeolion
`propulsion_bemt.airfoil_sections` CST fit (schema 1.7.0).

### Rotation sense

No config or code anywhere in the project stated the prop's rotation
sense — a genuine gap, not an overridden decision. Because the vehicle
carries a single, non-counter-rotating prop, the choice has no
aerodynamic/mass consequence in isolation, EXCEPT that it must be
*consistent with the existing blade twist geometry* — an arbitrary
label would silently contradict the twist law's own implicit handedness.

Verified numerically (not by symbolic sign-chasing, which is too easy
to get wrong here): for the twist law `beta(r) = atan(pitch/(2*pi*r))`,
a rotation vector along **body +x** (right-hand rule) gives every blade
station a small, physically sensible **positive** angle of attack and a
thrust reaction on the vehicle in +x ("forward, out the nose" per the
project's FRD convention), checked at r/R = 0.3/0.6/0.95 against both a
hover-like and a high-advance-ratio axial inflow. The opposite sign
gives an angle of attack near 180° at every station and every flow
regime tested — the blade flying backwards through its own relative
wind, not a subtle error. Equivalently: **clockwise viewed from aft (the
exhaust/−x end) looking forward toward the nose**; counter-clockwise
viewed from the nose looking aft.

This is recorded as `prop_geometry.ROTATION_AXIS_BODY_FRD = (1, 0, 0)`
and exported as `propulsion_bemt.rotation_axis` — the same unit-vector,
right-hand-rule idiom the schema already uses for `hinge_axis`, chosen
specifically to avoid relying on a verbal CW/CCW convention that
requires an assumed viewpoint (the same class of ambiguity ADR-0016's
placement and moment-reference-point fixes eliminated elsewhere in this
contract).

## Consequences

- `cad/prop_rotor.py` blade cross-sections change shape (Clark Y instead
  of the ad-hoc NACA-like taper); `build_prop_rotor` and
  `_blade_section_wire` now take a `ClarkYSection` parameter. `out/cad/`
  regenerates with a visibly different (but still watertight) blade
  profile; geometry tests re-verified against the new export.
- `propulsion_bemt.airfoil_sections` and `.rotation_axis` are **required
  within `propulsion_bemt`** from schema 1.7.0 onward (a
  version-conditional constraint, not merely documented as
  always-present) — the same discipline as the 1.5.0 placement and
  1.6.0 moment-reference-point fixes. `propulsion_bemt` itself remains
  entirely optional at every version.
- `config/prop_geometry.yaml`'s `camber_M`/`camber_P` keys are removed;
  `tc_root`/`tc_tip` are reinterpreted as thickness-scaling targets
  against the Clark Y reference, not NACA thickness-formula inputs.
- No design-point (MTOW/hover power/wing) change — this is a blade
  section/BEMT-fidelity and CAD-consistency fix, not a sizing change.
- Open item for later: this analysis stream (propeller section, BEMT
  contract, rotation sense) has grown enough in its own right that a
  dedicated notebook stage (parallel to `wing_design`/
  `control_vane_design`) may be worth splitting out of NB8's inline
  Aeolion-export block if it keeps growing — noted, not acted on here.

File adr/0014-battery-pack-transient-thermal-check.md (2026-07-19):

# ADR-0014: Battery pack mission-transient thermal check

Date: 2026-07-17
Status: Accepted (amended 2026-07-18 — see Amendment below)

## Context

ADR-0009 gave the airframe its two structural heat paths: the ESC
cold-plate and the vented battery bay. The battery-side model is a
steady-state **air-side capacity check** — a through-flow enthalpy
balance (`Q_batt = mdot·cp·dT_air`) that sizes the vents to carry the
heat away. It answers "can the bay reject the load" (yes, with ~40x
area headroom) but says nothing about how hot the **pack itself** gets,
because it has no thermal mass and no mission time axis.

An external battery-thermal review (C. Ucler, JETTAIL battery thermal
analysis, 2026-07) modelled exactly that: a lumped-capacitance pack
integrating its Joule heat `I²·R_pack` through two hover legs with
cruise cooling in between. The review's arithmetic was verified
line-by-line and is correct; its inputs predate the current design
point (2.60 kg / 900 W / the pre-freeze 554.6 g sized-LiPo mass), but
re-running the model at the frozen point changes the conclusion very
little — the halved heat rate is almost exactly offset by the lighter
pack's smaller thermal capacity plus the transition legs the review
omitted.

Two structural gaps in our model surfaced:

1. **`eta_bat = 0.97` implies a ~23 mOhm pack** (20 W loss at ~29 A
   hover). A real 6S1P 21700 pack is ~60–120 mOhm at the terminals
   (P50B DCIR ~10–13 mOhm/cell, plus welds, leads, connector). The
   nominal 90 mOhm case puts the hover battery loss at ~78 W — 4x the
   vent-model load.
2. **No transient pack model existed.** The pack's thermal time
   constant (~30 min against cruise cooling) is longer than the cruise
   leg, so the second vertical leg starts from an elevated temperature.
   At the ADR-0009 design ambient of 40 °C (hot day), the nominal-
   resistance case ends the mission at ~62 °C average — above the
   60 °C pack limit — before the review's 5–10 °C hot-spot allowance.
   The review itself used a 16 °C ambient, which masked this.

## Decision

Add the review's lumped-capacitance mission transient to
`thermal_design.py` (`battery_pack_transient`) and run it in NB7 as a
**reported, never filtered-on** check — the same discipline as the
ESC cold-plate and the COTS budget lines:

- Heat loads are derived: `I²·R_pack` at the wiring-law currents
  (`electrical_diagram.compute_operating_point`, the single call site
  for the current law). Only the resistance cases, pack specific heat,
  envelope estimate, and exposed-surface fraction are configured
  (`config/thermal.yaml`), each with a rationale.
- Mission structure comes from `config/mission.yaml`: two vertical
  legs of `t_hover/2 + t_transition/2` each (transitions billed at
  hover power, the mass-closure convention), adiabatic (hover bay
  airflow conservatively neglected), separated by `t_cruise` of
  laminar flat-plate cooling over `pack_exposed_frac` of the envelope
  at `V_cruise`.
- Three pack-resistance cases (optimistic 60 / nominal 90 /
  conservative 120 mOhm) until the built pack's DCIR is measured at
  procurement, after which the cases collapse to the measured value.
- Results land in `out/thermal.yaml` under `battery_transient:`;
  `design_summary` picks the nominal case up as a margins row and,
  while it exceeds the limit, as a standing finding. The regression
  tests pin the state (nominal FAILS, optimistic passes).

The steady-state vent model, its `Q_batt`, and the vent geometry
handed to CAD are **unchanged** — no back-edge into ADR-0009 outputs.

`eta_bat` in the mass closure is also unchanged for now: mission
energy is cruise-dominated, so the closure impact of the optimistic
hover efficiency is a few percent, and folding a measured value in is
a deliberate next-iteration change (it moves the design point and the
regression pins). The gap is documented in `config/battery.yaml`.

## Consequences

- New standing finding at the current design point: **the nominal
  90 mOhm pack ends the mission at ~62 °C average vs the 60 °C limit
  at 40 °C ambient** (optimistic 60 mOhm: ~55 °C, passes;
  conservative 120 mOhm: ~70 °C, fails clearly). Levers, in order of
  leverage: build/buy a low-resistance pack (measure DCIR; thick
  nickel+copper busbars on the in-country spot-welded build), duct
  part of the hover vent flow directly over the pack (the legs are
  modelled adiabatic — any hover-side convection is pure margin), or
  restrict operations at high ambient.
- The ground test of the review's §13 becomes the procurement
  acceptance step: run the mission current profile, measure pack DCIR
  and cell temperatures, then collapse `R_pack_mohm` to the measured
  value and re-pin.
- The model is a spatial average; cell cores and busbars run 5–10 °C
  hotter until validated by test.

## Amendment (2026-07-18): internal resistance folded into the model

The original decision left `eta_bat: 0.97` and the vent model's
`Q_batt = P_hover·(1/eta_bat−1)` unchanged, deferring the fold-in.
That deferral is now closed — the pack internal resistance is treated
consistently everywhere:

- **Mass closure**: `eta_bat` re-derived as the mission-averaged I²R
  efficiency at the nominal 90 mΩ pack on the 6S bus, **iterated to
  the closure fixed point → 0.916** (the heavier battery raises hover
  current, which lowers the efficiency again; hover legs ~0.86 at
  ~33 A, cruise ~0.98). The honest accounting moves the design point:
  **MTOW 2.303 → 2.518 kg, hover 652 → 743 W, sized pack 555 → 653 g
  (4.12 Ah)** — the true cost of a 90 mΩ pack, previously hidden by
  the 0.97 constant. A measured 60–70 mΩ build claws most of it back;
  that measurement is now worth ~150 g of MTOW, which is the whole
  argument for the review's §13 ground test.
- **Battery freeze consequence**: the margined ESC current
  (1.6 × 33.5 A = 53.6 A) outgrew the Molicel catalog entry's
  self-imposed 50 A derate — the freeze failed loudly, as designed.
  Resolution: the catalog rating is updated to the P50B cell's 60 A
  continuous datasheet value (`c_rate_cont: 12`) — a 1P stick's
  continuous limit is the cell's, provided the build specs adequate
  busbars. The actual mission draw is ~33 A (6.7C); the 1.6× ESC
  margin is the conservative element, not the pack.
- **Vent model (ADR-0009 path)**: `Q_batt = I_hover²·R_pack_nominal`,
  the same law as the mission transient, at the wiring-law hover
  current. The vent check and the transient now see the same hover
  heat (~80 W, not the old 20 W); the bay still vents with wide
  air-side headroom.
- The keep-in-sync rule: `eta_bat` (config/battery.yaml) and the
  `R_pack_mohm` nominal case (config/thermal.yaml) describe the same
  pack — when the DCIR is measured at procurement, update both from
  the measurement in one commit.

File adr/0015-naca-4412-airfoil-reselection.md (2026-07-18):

# ADR-0015: Airfoil re-selection — NACA 2412 → NACA 4412

Date: 2026-07-18
Status: Accepted

## Context

The v0.5.0 stall-consistency fix (external aero review, C. Ucler) made
`config/aerodynamics.yaml` `CL_max` track the selected airfoil's real
`CL_max_3D`. Because the wing sizing is stall-limited
(`W/S ≤ 0.5·ρ·V_stall²·CL_max` binds at the design point), section
lift now buys wing area directly — and the fix left two open items:

1. the NACA 2412 wing grew to 0.2107 m² / b 1.124 m, and its cruise
   CL (0.437) fell well below the polar optimum (~0.62), dropping
   cruise L/D to 12.76 with best-range speed ~16.7 m/s, below the
   20 m/s cruise;
2. the section ran with zero 2D→3D Cl_max headroom.

A trade study on this branch swept both levers:

**V_cruise** (16–22 m/s, through the mass closure): in the fixed-range
framing the closure is nearly V-independent — cruise energy is
`W·R/(L/D·η)` with the configured constant L/D — and MTOW moves only a
few tens of grams across the sweep. Changing V_cruise would ripple the
mission, CFD reference velocity, and every handoff for no modelled
gain. **Rejected.**

**Airfoil** (NACA 0012 / 2412 / 4412 / 2415 at the current design
point, MTOW invariant — the closure computes cruise power from the
conservative config `LD: 8.0`, so the airfoil affects wing geometry
and realized L/D, not the closure):

| section | CL_max_3D | W/S [N/m²] | S [m²] | b [m] | CL_cruise | L/D | V_MD [m/s] |
|---|---|---|---|---|---|---|---|
| 0012 | 0.949 | 83.6 | 0.2700 | 1.273 | 0.341 | 11.49 | 14.8 |
| 2412 | 1.219 | 107.2 | 0.2107 | 1.124 | 0.437 | 12.76 | 16.7 |
| **4412** | **1.489** | **131.2** | **0.1722** | **1.016** | **0.535** | **13.35** | **18.5** |
| 2415 | 1.287 | 113.3 | 0.1994 | 1.094 | 0.462 | 11.83 | 16.6 |

## Decision

Select the **NACA 4412** (`config/airfoil_selection.yaml`), with
`CL_max: 1.4886` in `config/aerodynamics.yaml` per the tracking rule.
**V_cruise stays 20 m/s** — with the 4412 wing, V_MD ≈ 18.5 m/s and
L/D at 20 m/s is within ~2% of the maximum, the same "near-optimum"
posture the original design card claimed.

The 4412 dominates the trade for this cruise-dominated mission
(config's own guidance: "good if endurance is the priority"): highest
cruise L/D, the smallest wing of any candidate — smaller than even the
pre-fix 2412 wing (b 1.016 vs 1.049 m), which un-does the v0.5.0 span
growth in CAD/structure — and the stall requirement met honestly at
the section's real lift.

## Consequences

- Wing: S 0.2107 → 0.1722 m², b 1.124 → 1.016 m, MAC 0.187 → 0.169 m;
  regression pins, `Allrun.case` (lRef/Aref/CofR), and the CAD exports
  move in the same commit. MTOW (2.303 kg), hover power (652 W), and
  the battery point are unchanged.
- Aileron re-sizes with the wing; the frozen KST servo margin is
  re-checked by the pipeline (requirement scales with the smaller
  chord/arm).
- **Watch — pitching moment**: the 4412's nose-down Cm0 (≈ −0.09 vs
  ≈ −0.05 for the 2412) is not modelled at this stage. Cruise pitch
  trim (vane deflection / CG placement at the 0.05 static margin) must
  be checked in the preliminary phase; this is the price of the camber.
- **Watch — low-Re Cl_max**: the empirical section Cl_max (1.654) is
  least certain exactly where it is now load-bearing, at
  Re ≈ 1.4×10⁵ near stall on a highly cambered section. The zero
  2D→3D headroom MARGIN warning in NB2 remains, by construction, for
  whichever section defines CL_max. Validate the wing's real CL_max
  (bench/flight or a XFOIL/CFD pass at stall Re) before freezing wing
  tooling; if it erodes, the honest response is re-running this
  selection with the measured value, not padding the config.

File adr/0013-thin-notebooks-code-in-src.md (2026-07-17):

# 13. Thin notebooks: all notebook code moves to src

Status: Accepted

## Context

ADR-0002 already requires all *physics* to live in `src/`, but by 2026-07
the fifteen notebooks had accumulated ~4,000 lines of Python anyway:

- an identical ~25-line path/matplotlib-style prelude in every notebook;
- an identical ~35-line "load every config, call `run_sizing_loop`"
  block in fourteen notebooks — the *"if you change the sizing API,
  update all fifteen call sites"* problem called out in CLAUDE.md;
- genuine physics that had leaked into notebooks in violation of
  ADR-0002: the entire jet-vane sizing model (NB3), the inertia
  primitives / assembly / battery-trim / BOM logic (NB9), the
  construction trade and sensitivity-sweep machinery (NB1);
- large matplotlib figure blocks and ASCII summary cards, including a
  ~70-line fuselage layout plot duplicated verbatim in NB6 and NB14 and
  a budget-margin chart duplicated in NB11 and NB15.

The notebooks are the rendered documentation (GitHub Pages); walls of
code bury the narrative they exist to tell.

## Decision

Notebooks contain **only** parameter setting, module calls, and short
interpretive prints. Everything else moves into `src/conceptual_design/`:

- `notebook.py` — `nb_setup()`: repo paths + house plot style + palette
  (the shared prelude as one call).
- `design_point.py` — `DesignInputs.from_config()` /
  `solve_design_point()`: the single call site for re-running the
  converged design point from `config/`; `load_handoff()` for `out/`
  reads. Sweeps override single inputs via `DesignInputs.solve(**kw)`.
- `control_vane_design.py` — NB3's vane physics (`VaneParams`,
  `design_vanes`, `mixing_check`, `write_control_vanes_yaml`).
- `mass_properties.py` — NB9's inertia primitives, assembly,
  battery-tray trim, BOM builder and handoff writer.
- `sizing_studies.py` — construction trade (ADR-0008), MTOW sensitivity
  sweeps, local elasticities; `vtol_power.climb_pw_terms()` exposes the
  P/W term breakdown NB1 used to re-derive inline.
- `plots/` — one module per notebook family; pure presentation, every
  function takes computed results and a save path and returns the
  Figure. The NB6/NB14 layout plot and NB11/NB15 budget chart exist
  once each here.
- `reports.py` and `design_summary.py` — the console tables and summary
  cards; NB15's margin table and standing-findings collection are logic
  and live in `design_summary.py`.

Design parameters that had been hardcoded in notebook cells (vane t/c,
hub ratio, servo safety factors, …) stay visible as notebook-set
parameters — now grouped in one commented `VaneParams`-style block per
notebook — so ADR-0002's "no magic numbers in src" holds.

**Exception:** NB8 (`vehicle_solid_model`) keeps its original inline
sizing block for now — it only executes in CI (CadQuery, Python 3.12),
so its conversion should land in a PR where CI can actually run it.

## Verification discipline

The refactor was landed with a byte-diff gate: after each notebook's
conversion the pipeline re-ran it and every `out/*.yaml` / `bom.csv`
handoff had to be byte-identical to the committed baseline (modulo CRLF
on Windows checkouts). The full 14-notebook pipeline, the design
regression + geometry pins, and ruff all pass unchanged. The same
discipline applies to future extractions: moving code between notebooks
and `src/` must not move a single number.

## Consequences

- Notebook code drops from ~4,050 to roughly a third of that; rendered
  pages read as narrative with parameter blocks and results.
- A sizing-API change now touches `design_point.py` (plus NB8's block)
  instead of fifteen notebooks.
- Physics extracted from NB3/NB9 becomes importable and unit-testable.
- The notebooks import more names per cell; the coupling is explicit
  (`from conceptual_design.plots import …`) rather than copy-pasted.

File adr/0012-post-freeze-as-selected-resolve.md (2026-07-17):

# 12. Post-freeze as-selected re-solve as new downstream notebooks

Status: Accepted

## Context

NB4 (`aileron_design`), NB5 (`vibration_isolation`), and NB6
(`fuselage_design`) size against configured estimates — a 12 g servo
class, a 60 g FC/IMU cluster, a 1500 kg/m³ effective pack density —
because nothing better exists before hardware is chosen. NB11
(`cots_selection`, ADR-0011) then freezes real parts with catalog masses
and envelopes, and immediately exposes the gaps: the Gens Ace pack is a
rigid 137 mm brick 58 g over the sized battery mass, the motor is ~99 g
over its allocation, the avionics stack is 42 g over the net bay budget.

The obvious move — feed the frozen hardware back and re-run NB4–NB6 — has
already been rejected in principle: ADR-0001 makes the pipeline one-way
precisely so that a change's provenance is always visible. Re-running the
old notebooks with new inputs would overwrite the conceptual solution
(the record of what the estimates gave), silently move the geometry the
CAD/CFD chain and the regression pins are built on, and create a
NB11 → NB4 back-edge that turns the pipeline into a loop.

## Decision

Re-solve the estimate-based designs **after** the freeze, as **new
notebooks appended to the pipeline**, followed by a read-only summary:

- NB12 `aileron_design_cots` — NB4's physics with the frozen servo
  (catalog mass; torque check against real stall) → `out/aileron_cots.yaml`
- NB13 `vibration_isolation_cots` — NB5's physics with the frozen FC mass
  (blade count consistency-checked against the frozen prop)
  → `out/vibration_cots.yaml`
- NB14 `fuselage_design_cots` — NB6's physics with as-selected masses,
  the pack density derived from the frozen battery's own envelope, each
  bay's length **floored at the best-orientation axial length of the
  rigid part it holds**, actual motor/prop/ESC masses in the layout, and
  a physical-fit report for every frozen part → `out/fuselage_cots.yaml`
- NB15 `design_summary` — the last notebook: reads only `out/` handoffs,
  writes nothing; rolls up the design point, the margins, the frozen
  hardware list, and **every standing finding collected programmatically
  from the handoffs**.

Supporting physics lives in `src/conceptual_design/cots_integration.py`
plus backward-compatible extensions to `fuselage_design.py`
(`part_envelopes`, `prop_item_masses`, `min_axial_length_m`); the
`*_cots.yaml` handoffs reuse the NB4–NB6 writers and schemas so consumers
read either solution identically.

Rules of the stage:

- **No back-edges.** The conceptual `out/{aileron,vibration,fuselage}.yaml`
  are untouched; CAD (NB8), CFD, and the `Allrun.case` reference values
  stay on the conceptual geometry.
- **Deltas are findings, not feedback.** The re-solve reports them
  (`delta_vs_conceptual`, `bay_fit`, `as_selected` blocks, pinned by the
  regression tests) exactly like the ADR-0009 thermal finding and the
  NB11 allocation findings. Folding a delta into `config/` is a
  deliberate, reviewed design iteration — after procurement weighs the
  real parts — from which the whole pipeline re-converges.
- **Fit is reported, never filtered on** — same discipline as NB11's
  mass-allocation report; a misfit indicts a packaging assumption, not
  the part.

## Consequences

- The pipeline is fifteen notebooks; NB2–NB15 all re-run
  `run_sizing_loop`, so a sizing API change now touches fifteen call
  sites (was eleven).
- At the current design point the re-solve is materially informative:
  the as-selected all-up mass is **2.427 kg (+125 g over the 2.303 kg
  closure)**, and the hull that actually holds the rigid battery grows
  to **⌀106 × 531 mm** (from ⌀96 × 478 mm), pushing the structure model
  ~33 g over the structural fraction — three new pinned standing
  findings on top of the freeze's allocation findings.
- Two designs coexist by construction (conceptual vs as-selected). The
  regression tests pin both and the relation between them (the
  as-selected hull may never be smaller); the summary notebook makes the
  gap impossible to overlook in every CI run and release snapshot.
- `config/fuselage.yaml` gains `part_clearance_m` (axial clearance per
  rigid part in a bay) — the one new configured physical parameter.

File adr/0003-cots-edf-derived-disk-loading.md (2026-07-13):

# 3. COTS 195 mm EDF; disk loading derived, not configured

Status: Accepted — **amended 2026-07-12**: the COTS rotor is a 3-blade
propeller (203 mm) in the airframe duct, not an EDF cartridge; the
derived-disk-loading principle is unchanged.

## Context

The propulsor is the single most design-driving component of an EDF
tail-sitter. Two paths exist: develop a custom fan sized to a chosen disk
loading, or adopt a commercial off-the-shelf (COTS) EDF and let the vehicle
size around it. Custom-fan development is out of scope for a conceptual
university study and would make disk loading a free variable that the sizing
loop could game.

## Decision

- Adopt a **COTS 195 mm EDF** (Schübeler DS-215 class). Rotor diameter is a
  fixed input (`config/rotor.yaml`), not a sizing degree of freedom.
- **Disk loading is derived** (`DL = MTOW·g / A`), never configured — it
  falls out of the converged MTOW and the fixed disk area.

## Consequences

- Hover power and thrust margin follow from a real, purchasable fan, so the
  design point is buildable rather than notional.
- Because disk loading is high for this class, hover is expensive; this
  drives the deliberately short-hover mission profile (see the mission
  design decision) rather than the other way around.
- The parametric prop rotor in CAD is for visualisation and rotating-zone
  CFD only; vehicle aero CFD models the fan as an actuator disk, so the
  external-aero STL deliberately excludes the blades.
- Swapping EDF class is a single-config change that re-converges the whole
  design through the pipeline.

## Amendment (2026-07-12): COTS 3-blade prop in the airframe duct

### Context

The COTS component selection stage (NB11, `config/components/`) put real
hardware against this decision and found that **the 195 mm COTS EDF class
has no light implementation**. The only purchasable unit at that diameter
is the Schübeler DS-215-DIA heavy-lift family — the full HST power unit is
3.4 kg, heavier than the whole aircraft, and even the fan alone (EST
~1 kg) plus the lightest plausible motor lands ~6× over the propulsion
mass allocation (−1069 g at the 2.376 kg design point). The original
decision was buyable only as hardware sized for 20 kg-class jets.

Meanwhile the vehicle never needed an EDF's high disk loading: the design
runs deliberately low disk loading, and the configured rotor solidity
(0.077) always corresponded to a ~3-blade propeller over the exposed
annulus outside the 0.4 R hub — the sizing physics was modelling a prop
all along; only the procurement assumption said "EDF cartridge". A
prop-in-duct is also what the actual V-BAT flies. COTS 3-blade sizes
bracket 195 mm (7" = 178 mm, 8" = 203 mm), so keeping 195 mm would mean a
custom rotor — exactly what this ADR exists to avoid.

### Decision

- The COTS rotor is a **3-blade 8×6-class propeller (203 mm, e.g. Master
  Airscrew 3-blade 8×6, ~23 g)** running in the airframe's own duct (the
  duct was always airframe structure; the exhaust centerbody keeps
  housing the vane servos, the prop mounts to the motor via an adapter).
- `D_rotor_m` moves 0.195 → **0.203** and the whole design re-converges
  through the pipeline (this amendment's commit carries the new pins).
- **Disk loading stays derived** — the principle of this ADR is
  unchanged; only the rotor hardware class moved.
- The `T_max_N` guard is re-derived for the prop-in-duct: momentum-theory
  static thrust at the selected motor's power ceiling
  (`T = (P_shaft · FM · sqrt(2 ρ A))^(2/3)` ≈ 35 N), replacing the
  DS-215-class 50 N.
- Rotor solidity (0.077) and figure of merit (0.70) are retained — both
  are consistent with a 3-blade prop in a duct — but now carry an
  explicit verify-at-procurement note; the empirical RPM law was always a
  propeller law.

### Consequences

- Propulsion mass closes: motor + prop ≈ 306 g against a ~210 g
  allocation is a finding of ~100 g, versus ~1.3 kg of unbuyable
  hardware before. NB11 selects the prop; the DS-215 fan remains in the
  database as the diameter-rejected documentation of this amendment.
- Slightly larger disk (+8% area) lowers hover disk loading and induced
  power; all regression pins, `cfd/vehicle/Allrun.case`, and the `px4/`
  provenance values move in this commit (ADR-0011 discipline).
- The parametric CAD rotor becomes a 3-blade prop
  (`config/prop_geometry.yaml`); `out/cad/` regenerates in CI.
- Duct aero (tip clearance at 203 mm, augmentation) and the prop's
  power limit (~900 W class vs the EDF's kilowatts) are the new risks to
  retire on the thrust stand (ADR-0011 stage a).

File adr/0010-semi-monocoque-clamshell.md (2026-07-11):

# 10. Semi-monocoque clamshell fuselage

Status: Accepted (amends ADR-0008's split-line architecture)

## Context

Design review (Çağlar Üçler, 2026-07-09) of the ADR-0008
airframe — a load-bearing monocoque cylinder with transverse splits
(removable nose, 90° battery hatch) — proposed a fundamentally better
structural architecture for manufacturability, access, and mass:

- Build the fuselage as **two half-moons** (longitudinal clamshell):
  far easier to mold or print than a closed cylinder.
- Run a **rectangular Alu/composite profile around the joint line**: it
  works as the **longerons** (a "picture frame" in plan view). Add
  **crossbeams** between the longerons and anything can be mounted
  anywhere — the camera/payload bolts to the frame, so no separate nose
  module is needed.
- Put the **battery rail on the lower centerline (180°)** and tie it to
  the frame with **2 half-rings**; the rings double as the longeron↔
  frame connection and a structural vibration path.
- Make the **upper half a full-length lid** — hinged on one longeron,
  latched on the other — for one-motion interior access.
- Result: **semi-monocoque** — the frame carries the loads, the skin
  thins to a covering — *lighter than the load-bearing cylinder*,
  finishing at **2-ply carbon** ("2 kat karbonla biter").

Follow-up review point (Onur Tuncer): the same architecture is FDM-printable —
there is no harm printing what could be laid up in carbon, especially in
first iterations; later a mold can itself be printed. So the
architecture is **construction-agnostic**; only skin/frame material
properties switch.

## Decision

1. **Longitudinal clamshell replaces the transverse splits.** The lid
   runs from the nose tip to `clam_aft_frac·L` (the tail-cone start —
   the boattail is the fan centerbody and stays one piece with the
   lower half). ADR-0008's removable nose and battery hatch are
   superseded; the two-piece wing on the CFRP carry-through spar is
   unchanged.

2. **Explicit semi-monocoque member model** replaces the monocoque
   area-density estimate (`m_shell = k_struct·ρ·t·S_wet`, k_struct=1.30):

       m_struct = k_skin·ρ_skin·t_skin·S_wet        (skin, k_skin=1.05)
                + λ_frame·(2·L_clam + 2·D)          (longeron frame)
                + λ_frame·n_cross·0.8·D             (crossbeams)
                + λ_frame·n_rings·π·D/2             (half-rings)

   λ_frame is computed from the box-profile section × material density —
   never configured as mass. The old k_struct=1.30 hid the frames inside
   a knock-up factor; they are explicit members now, so only the
   bonding/overlap allowance (k_skin=1.05) remains on the skin.

3. **Per-method skin table** (`config/modularity.yaml`): the model is
   evaluated for the configured `construction_method` AND for both skin
   options on every run, keeping the print-first/carbon-later trade
   visible:

   | structure | mass @ 3.06 kg design point |
   |---|---|
   | old monocoque estimate (0.8 mm × 1.30) | 256 g |
   | semi-mono, FDM skin (1.2 mm) + Alu frame | **352 g** |
   | semi-mono, 2-ply CFRP skin (0.5 mm) + Alu frame | **242 g** |

   The FDM clamshell is *heavier* than the old estimate but buildable
   immediately with full interior access; the carbon skin realizes the
   predicted mass gain — exactly the review's sequencing.

4. **Packaging wall decoupled from structural skin.** `t_shell_m`
   (config/fuselage.yaml) remains the conservative packaging allowance
   for the internal bay radius, so bay geometry (and every geometry pin)
   is stable across skin material choices at conceptual stage.

5. **Joint hardware** carve (ADR-0005 discipline) is now the lid's
   hinge strip + latches; the battery rail keeps its existing tray
   mass/travel model (its physical description moves to the lower
   centerline, tied to the frame by the half-rings).

## Consequences

- Structural budget utilization drops to ~61% (352 g FDM against the
  574 g budget) — grounds for a follow-up **re-baseline decision**
  (lower `fs_base` and/or `k_construction` with the explicit model as
  justification), which would shrink MTOW. Deliberately deferred to its
  own decision with these numbers on the table.
  **Executed (2026-07-11):** `fs_base` fitted 0.25 → 0.22 so the budget
  lands at ~110% of the FDM member estimate after full re-convergence;
  MTOW **3.06 → 2.376 kg** — lighter than the original 2.5 kg monocoque
  baseline, i.e. the semi-monocoque architecture more than pays back the
  FDM print penalty at the whole-vehicle level. The feasible floor
  (~0.19) is set by the ADR-0005 guards: the shrunk avionics budget must
  still carry the fixed servo/isolator hardware.
- CAD: `fuselage_lid`/`fuselage_lower` replace nose/main/hatch; the
  frame (longerons, crossbeams, half-rings, battery rail) is modeled as
  assembly-only display parts; the fused external-aero STL is unchanged
  in shape.
- The vibration-isolation model (ADR-0007) is unchanged; the half-rings'
  structural damping role is a modeling refinement left for a future
  pass.
- Equipment mounting generalizes: anything bolts to the frame/crossbeams
  — the packaging model keeps its bay abstraction, which now has a
  physical carrier.

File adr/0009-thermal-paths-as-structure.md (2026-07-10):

# 9. Thermal paths as structure

Status: Accepted

## Context

The airframe carries two continuous heat sources in hover — the ESC
(~50 W switching/conduction loss) and the battery (~30 W pack IR loss) —
and had no thermal model at all (`docs/assumptions.md` listed "no thermal
limits"). The ESC was a lumped mass with a bare "cooling air is available"
comment; the battery bay was a sealed packed cylinder.

Heat-rejection paths are cheap to plan into the current geometry and
expensive to retrofit once the shell is frozen: the ESC already sits
mid-body in the fan's inflow field, and the battery-bay wall is free to
vent. The decision is to size both **now**, as structure that also does
thermal management.

## Decision

1. **Model both paths as structure, first-order** (new `thermal_design`
   stage, NB7). Heat loads are **derived**, not configured:
   `Q_esc = P_hover·(1 − eta_esc)`, `Q_batt = P_hover·(1/eta_bat − 1)`.
   Cooling airflow is a configured fraction of the fan induced velocity
   `v_h = sqrt(W / (2 ρ A_disk))`.
   - **ESC cold-plate**: flat-plate forced convection off a plate on the
     inflow-washed inner wall. Square-plate Nusselt closes in one step:
     `A_req = (Q_esc / (C_h · ΔT))^(4/3)`.
   - **Vented battery bay**: through-flow energy balance
     `Q_batt = ρ V_vent A_vent cp ΔT_air` → required vent area.

2. **No mass re-baseline.** The ESC cold-plate is absorbed into the
   existing ESC/propulsion "mounts" allocation (the propulsion fraction
   already covers "motor + ESC + EDF fan + mounts"); the vents remove a
   little skin. `thermal_design` guards that the plate fits inside that
   allocation rather than carving new mass. The design point stays 3.06 kg.

3. **CAD parts are assembly-only** (excluded from the fused external-aero
   STL, like the spar tube and soft-mount trays): an `esc_cold_plate`
   wall segment and a `battery_vents` louvre bank. The external-aero model
   treats the skin as closed — consistent with the actuator-disk fan
   convention — so the fused STL, CFD case, and geometry pins are unchanged.

4. **Report margins, don't mask them.** Where a path is tight, surface it
   as a finding rather than forcing a pass.

## Consequences

- **Battery bay: comfortable** — ~2 cm² of vent needed against ~90 cm² of
  bay wall (~40× headroom), ~20 °C margin at 40 °C ambient. Genuinely free
  in the current geometry.
- **ESC cold-plate: marginal, and it breaks assumption 2's premise** — at
  the 3.06 kg / ~1 kW-hover point the ~50 W ESC loss needs a ~350 cm²
  (~186 mm) plate that masses ~190 g, **exceeding the ~115 g ESC
  allocation**, with only a few °C margin cooling mid-body at half the
  induced velocity. `out/thermal.yaml` records `ok: false` for the ESC
  path; the notebook prints the finding and the levers (a higher-efficiency
  ESC drops the load to ~20 W; the ESC nearer the inlet cools better at a
  CG cost; a finned spreader; or a larger propulsion fraction). This is a
  standing design finding for the next pass, deliberately not resolved by
  tuning config to a false pass.
- Zero churn elsewhere: no mass move, no CG shift, no CFD/geometry-pin
  change. `TestThermal` pins the (marginal) ESC state and the (healthy)
  battery state so a future drift in either is caught.

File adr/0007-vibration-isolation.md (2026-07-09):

# 7. Soft-mount the FC/IMU and payload against EDF imbalance

Status: Accepted

## Context

The single EDF is a high-RPM rotating machine bolted to a stiff CFRP
monocoque. Its dominant forcing is the 1-per-rev shaft imbalance at the shaft
frequency (~211 Hz at the hover design point, derived from rotor RPM via
`rpm_from_diameter`); blade-pass (×11) is far higher. That 1/rev line
corrupts the IMU attitude estimate and blurs the EO payload. Until now the
FC/IMU and payload were rigid internal bays with no isolation modeled.

The isolators cost mass and, because they need rattle space, packing volume —
and the fuselage is packaging-constrained at 100% bay-stack utilization, so
any volume demand shows up in the geometry. This is a conceptual-stage
decision precisely because that volume is cheap to reserve now and painful to
retrofit.

## Decision

- Soft-mount the **FC/IMU cluster** and the **payload** each as a 1-DOF
  base-excitation isolator, sized in `vibration_isolation.py` (new NB5).
- Size the isolator corner frequency `f_n` as high (stiffest, least sway) as
  still meets a target transmissibility at the 1/rev forcing, and require it
  to sit in a valid window: above the flight-control bandwidth (a mount
  softer than the control loop would let the FC chase its own sway) and below
  `f_forcing/√2` (the isolation threshold).
- Feed the sway/rattle space into the fuselage bay stack (`sway_pad_m`) and
  carve the isolator hardware from the fractions that document it — FC-tray
  isolators from avionics, payload-mount isolators from structure — using the
  same carve-out/guard machinery as the vane and aileron hardware
  (ADR-0005).
- Model both soft-mounted modules in the CAD assembly (isolator standoffs +
  rattle gap) as **assembly-only** internal parts — not fused into the
  external-aero STL, following the prop-rotor precedent.

## Consequences

- Because the forcing is far above any practical corner frequency, the sized
  mount (f_n ≈ 58 Hz, ~90% attenuation of the 1/rev) needs only ~0.1 mm
  static deflection and a few mm of sway — the packing cost is small, and in
  fact the fuselage shrank marginally (the isolator mass carved out of
  avionics reduces packed volume more than the sway pad adds length).
- The FC/IMU isolated mass (`m_fc_imu_kg`) is a config parameter: only the
  vibration-sensitive electronics are soft-mounted, not the whole avionics
  fraction.
- `out/vibration.yaml` becomes a pipeline handoff; `fuselage_design`,
  `mass_properties`, and `vehicle_solid_model` all consume it.
- The transmissibility model is 1-DOF and linear; real multi-axis coupling,
  resonance dwell on spin-up, and isolator nonlinearity are out of scope at
  the conceptual stage.

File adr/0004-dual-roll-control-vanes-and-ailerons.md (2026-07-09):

# 4. Dual roll control: jet vanes (hover) + ailerons (cruise)

Status: Accepted

## Context

Jet control vanes in the EDF exhaust provide pitch/yaw/roll for the
tail-sitter and are sized from **hover** thrust. Vane authority is driven by
jet dynamic pressure, `q_jet = T / A_disk` (actuator-disk momentum theory),
which scales linearly with thrust. In wing-borne cruise the EDF only needs to
overcome drag, so cruise thrust is roughly `L/D⁻¹` of hover thrust (~6% at
this design point). Vane roll authority therefore collapses from a large
hover margin to a thin cruise margin over the long (~900 s) cruise leg — a
previously unexamined risk.

## Decision

- Keep **jet vanes primary for all three axes in hover and transition**,
  where aerodynamic surfaces are ineffective.
- Add **ailerons as the primary roll actuator in cruise**. Aileron authority
  is driven by *wing* dynamic pressure, independent of EDF throttle, so it is
  strong exactly where vane authority is weak.
- Vanes remain available as a cruise roll backup; nothing is removed.
- Both `control_vane_design` and `aileron_design` check against a single
  shared requirement, `ddot_min_deg_s2` in `config/aerodynamics.yaml`.

## Consequences

- Adds a fourth pipeline stage (`aileron_design`, NB4) and its own
  config/handoff; fuselage/CAD/mass/wiring shift down one number.
- Ailerons are sized deliberately small (12% span / 12% chord): textbook GA
  proportions would give a >100× authority margin and an unrealistic servo
  torque at this vehicle's cruise q and wing arm.
- Introduces two more servos into the mass budget, CAD, and wiring diagram;
  aileron servos mount as lower-surface pods because the thin wing cannot
  bury them at the hinge.
- Roll is now a two-actuator system across the flight envelope; any future
  control-allocation/mixing work must account for the hover→cruise handoff.

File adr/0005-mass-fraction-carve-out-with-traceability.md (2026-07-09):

# 5. Mass-fraction carve-out with traceability and a guard

Status: Accepted

## Context

Early mass closure uses top-down weight fractions
(`config/initial_weight_fraction_estimation.yaml`): structural, propulsive,
avionics, misc, each a fraction of MTOW. As real hardware is identified
(vane servos, aileron servos, linkages, battery tray), its mass must move
from an anonymous fraction to a named, positioned line item — without
double-counting and without silently discarding the original top-down
assumption that justified the fraction.

An early attempt netted named hardware straight out of the `misc` fraction
with only a `> 0` check. This hid two problems: the fraction's documented
scope was ignored (servos belong to avionics, not misc), and a carve-out
could quietly exceed what the fraction was ever meant to hold.

## Decision

- Carve each piece of named hardware from the **fraction that documents it**:
  servos → avionics, vanes/linkages → structural, battery tray → misc — as
  each fraction's own comment in the config describes its scope.
- **Keep both numbers on the handoff**: the original fraction budget and the
  carved amount (and the net remainder), so the history of the top-down
  assumption is never lost — only the *net* line item shrinks.
- **Guard the carve-out**: a named module constant
  (`MAX_HARDWARE_CARVE_FRACTION`) asserts a carve-out cannot exceed a
  documented share of its budget; exceeding it fails loudly, signalling the
  fraction assumption itself needs revisiting rather than a silent net-down.

## Consequences

- Mass closes exactly, and every named item is traceable to the fraction it
  came from, with the original budget still visible for review.
- A design change that overloads a fraction (e.g. control hardware growing
  past its avionics share) surfaces as a hard failure, not a quiet drift.
- Adds bookkeeping fields to the fuselage handoff and a small amount of
  carve-out logic, accepted as the cost of not losing the sizing history.

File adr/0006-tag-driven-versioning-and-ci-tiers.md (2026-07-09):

# 6. Tag-driven versioning and tiered CI

Status: Accepted

## Context

The design point drifts as models and config evolve, and CAD/CFD outputs are
expensive to regenerate (CadQuery needs Python 3.12; converged CFD needs real
hardware). We need versions that cannot be hand-edited out of sync with the
code, and a CI strategy that validates the whole pipeline without ever
attempting production CFD on shared runners.

## Decision

- **Version comes from git tags via `setuptools-scm`** — never edited by
  hand. A frozen design snapshot is a `v*` tag.
- **Three CI tiers:**
  - `ci.yml` — ruff, pytest (3.10/3.12/3.14), ShellCheck on `cfd/**/Allrun*`.
  - `design-pipeline.yml` — executes all eight notebooks, runs
    design-regression + geometry tests, uploads `out/`; on `main` also runs
    the coarse OpenFOAM smoke run and deploys the GitHub Pages report.
  - `release.yml` — a `v*` tag re-runs the pipeline and attaches the frozen
    snapshot to a GitHub Release.
- **Never run full/converged CFD in CI.** The coarse-mesh, 60-iteration
  smoke run validates case *setup* only and is the ceiling.
- Regression pins (`tests/test_design_outputs.py`) lock the design point and
  cross-check `cfd/vehicle/Allrun.case`; an intentional design change updates
  the pins and Allrun.case in the same commit.

## Consequences

- A release is reproducible: the tag pins the code, and the pipeline
  regenerates `out/` from `config/` to prove it still converges.
- CadQuery-dependent outputs (`out/cad/`) are validated against a fresh CI
  regeneration; committed copies may lag locally (the 3.14 venv can't build
  them) but CI is the source of truth.
- Each version tag is accompanied by a `CHANGELOG.md` entry (project policy).
- CI cost is bounded and predictable; expensive converged CFD stays off-CI on
  the user's own hardware.

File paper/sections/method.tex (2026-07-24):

\section{Method}
\label{sec:method}

The methodology's central idea is a strict division of labor between
three actors, mediated by a version-controlled repository that is the
single source of truth for the design
(Fig.~\ref{fig:workflow}):

\begin{enumerate}[nosep,label=(\roman*)]
\item \textbf{Deterministic physics code} is the \emph{only} source of
  engineering numbers. Every sizing relation, mass model, and margin
  check is transparent, configured Python under regression test. No
  quantity used in a design decision is ever generated by the language
  model itself.
\item \textbf{The AI agent} --- an LLM-based agentic coding tool
  \citep{anthropic2025claudecode} with full read, write, and execute
  access to the repository --- writes, refactors, and re-converges
  that code,
  propagates design changes across every affected discipline, drafts
  decision records and documentation, and executes the analysis
  pipeline. It is an engineering \emph{collaborator}, not an oracle:
  its contributions are ordinary commits subject to the same review
  and testing gates as human-written ones.
\item \textbf{Human engineers} set requirements, issue design
  directives in natural language, review every change (via pull
  requests), perform independent expert review of the evolving design,
  and accept or reject each recorded decision.
\end{enumerate}

Sections~\ref{sec:pipeline}--\ref{sec:iteration} describe the four
pillars that make this collaboration rigorous: a one-way analysis
pipeline, a machine-readable governance layer, a verification harness
that the AI cannot silently bypass, and an interaction protocol with
full provenance.

\begin{figure}[htbp]
\centering
\resizebox{\textwidth}{!}{%
\begin{tikzpicture}[
  font=\small,
  node distance=5mm and 9mm,
  box/.style={draw, rounded corners=2pt, align=center, minimum height=8mm,
              inner sep=2.5mm, fill=gray!8},
  actor/.style={draw, align=center, minimum height=8mm, inner sep=2.5mm,
                fill=blue!8, rounded corners=2pt},
  gate/.style={draw, align=center, minimum height=8mm, inner sep=2.5mm,
               fill=orange!12, rounded corners=2pt},
  arr/.style={-{Stealth[length=2.2mm]}, thick}
]
% pipeline row
\node[box] (config) {\code{config/*.yaml}\\design inputs};
\node[box, right=of config] (src) {\code{src/}\\physics library};
\node[box, right=of src] (nb) {\code{notebooks/}\\16-stage pipeline};
\node[box, right=of nb] (out) {\code{out/}\\typed hand-offs};
\node[box, right=of out] (cfd) {CAD / CFD /\\flight-stack\\consumers};
\draw[arr] (config) -- (src);
\draw[arr] (src) -- (nb);
\draw[arr] (nb) -- (out);
\draw[arr] (out) -- (cfd);
% actors row
\node[actor, above=11mm of src] (human) {Human engineers\\directives, review,\\expert findings};
\node[actor, above=11mm of out] (ai) {AI agent\\implements, re-converges,\\documents};
\draw[arr, <->] (human) -- node[above]{natural language} (ai);
\draw[arr] (ai.south) -- ++(0,-4mm) -| (nb.north);
\draw[arr] (human.south) -- ++(0,-4mm) -| (config.north);
% gates row
\node[gate, below=11mm of src] (gov) {Governance\\constitution (\code{CLAUDE.md}),\\ADRs, changelog};
\node[gate, below=11mm of out] (ver) {Verification\\design-point pins, CI\\full-pipeline re-execution};
\draw[arr, <->] (gov) -- (ver);
\draw[arr] (gov.north) -- ++(0,4mm) -| (src.south);
\draw[arr] (ver.north) -- ++(0,4mm) -| (out.south);
\end{tikzpicture}%
}
\caption{The governed human--AI--repository loop. Engineering numbers
flow only left-to-right through the deterministic pipeline (top row);
the AI agent and human engineers modify the repository under the
governance and verification gates (bottom row).}
\label{fig:workflow}
\end{figure}

\subsection{The design repository as a one-way analysis pipeline}
\label{sec:pipeline}

All design knowledge lives in one repository with a strictly one-way
dataflow:
\begin{equation*}
\code{config/} \;\rightarrow\; \code{src/} \;\rightarrow\;
\code{notebooks/} \;\rightarrow\; \code{out/} \;\rightarrow\;
\text{CAD/CFD/flight-stack consumers.}
\end{equation*}
Every physical parameter --- mission times, aerodynamic limits,
battery properties, structural factors --- lives in commented YAML
configuration files with a written rationale; the Python physics
library contains \emph{no} magic numbers. Jupyter notebooks are thin
orchestration only (parameters, module calls, interpretation); all
physics, plotting, and reporting code lives in the importable library,
so the entire design is reproducible headlessly and testable by unit
tests. Each pipeline stage writes typed YAML/JSON hand-off files that
downstream stages read, and no stage ever writes back upstream. In the
case study this pipeline comprises sixteen notebook stages
(Table~\ref{tab:pipeline}), executed in dependency order.

This architecture is not incidental to the AI methodology --- it is
what makes an LLM agent safe to employ. Because the dataflow is
one-way and fully regenerable from \code{config/}, the agent can be
asked to re-converge the whole design after any change, and the effect
of the change is completely observable in the diff of the generated
hand-offs. Because notebooks are thin, the agent's edits concentrate
in ordinary, reviewable, unit-testable Python modules rather than in
opaque notebook state.

\begin{table}[htbp]
\centering
\caption{The sixteen-stage analysis pipeline of the case study. Each
stage writes typed hand-offs to \code{out/} that later stages consume;
stages 13--15 re-solve stages 4--6 with the frozen commercial hardware
without touching the conceptual outputs (no back-edge).}
\label{tab:pipeline}
\small
\begin{tabularx}{\textwidth}{@{}rlX@{}}
\toprule
\# & \textbf{Stage} & \textbf{Function} \\
\midrule
1 & Conceptual design & Mission sizing and iterative mass closure (MTOW, wing, power) \\
2 & Wing design & Airfoil selection and wing geometry \\
3 & Control vane design & Jet-vane sizing from hover thrust \\
4 & Aileron design & Cruise-phase roll authority (backup to vanes) \\
5 & Vibration isolation & FC/IMU and payload soft mounts vs.\ 1/rev rotor forcing \\
6 & Fuselage design & Packaging, center of gravity, drag trade \\
7 & Thermal design & ESC cold plate, vented battery bay, pack mission transient \\
8 & Vehicle solid model & Parametric CAD (STEP/STL export) \\
9 & Aerodynamic hand-off & Versioned JSON geometry contract for external VLM/BEMT analysis \\
10 & Mass properties & Inertia tensor, bill of materials, CG trim \\
11 & Wiring diagram & Generated electrical block diagram from the sizing result \\
12 & COTS selection & Deterministic component freeze against derived requirements \\
13--15 & As-selected re-solve & Stages 4--6 re-solved with frozen hardware masses/envelopes \\
16 & Design summary & Pure reader: design point, margins, standing findings \\
\bottomrule
\end{tabularx}
\end{table}

\subsection{Governance: a machine-readable project constitution}
\label{sec:governance}

The AI agent is steered by a \emph{project constitution} --- a
repository file (\code{CLAUDE.md}) that the agent loads at the start
of every working session and that encodes the engineering rules of the
program in plain language. In the case study it fixes, among others:

\begin{itemize}[nosep]
\item \textbf{No magic numbers}: every physical parameter lives in
  configuration with a commented rationale; numerical tolerances and
  named guard limits are the only exceptions.
\item \textbf{All physics in the library}: notebooks only set
  parameters, call modules, and interpret results.
\item \textbf{Conventions}: a single body-fixed axis convention
  (front--right--down) and unit discipline (SI in hand-offs and module
  interfaces; millimetres only inside CAD exports) applied uniformly
  across sizing, CAD, CFD, and documentation.
\item \textbf{Analysis-cost policy}: continuous integration validates
  CFD case \emph{setup} with a coarse smoke run only; converged CFD is
  never run in CI.
\item \textbf{Documentation duties}: every architecturally significant
  decision gets an architecture decision record (ADR); every tagged
  version gets a changelog entry.
\end{itemize}

Because the constitution is versioned alongside the code, the rules
evolve by the same review process as the design itself, and a new
human collaborator or a fresh AI session inherits identical
constraints. Design decisions are captured at decision time as ADRs
(status/context/decision/consequences); superseded decisions are never
rewritten but amended by new records, preserving the full reasoning
trail. In the case study the AI drafted each ADR as part of
implementing the corresponding change, and the human engineers
accepted or revised it in review --- eighteen ADRs over the program,
covering choices from ``all physics in \code{src/}'' to the propeller
blade section.

\subsection{Verification: making silent design drift impossible}
\label{sec:verification}

Three mechanisms ensure that neither the AI nor a human can move the
design unintentionally:

\paragraph{Design-point regression pins.} The converged design point
--- masses, geometry, control-surface torques, CFD reference values
--- is pinned in the test suite (147 test functions in the case
study). An \emph{intentional} design change must update the pins in
the same commit, which makes the diff itself the documentation of the
new design point; an \emph{unexpected} pin failure means the design
drifted and blocks the merge. This converts the classic LLM risk of
plausible-but-wrong output into a loud, reviewable event.

\paragraph{Full-pipeline continuous integration.} Every pull request
re-executes all sixteen notebook stages from scratch, runs the
regression and geometry tests (e.g., watertightness and unit checks on
exported CAD), and archives the regenerated hand-offs. On the main
branch, a coarse CFD smoke run additionally validates the OpenFOAM
case setup against the current geometry. Pushing a version tag
freezes a complete design snapshot (YAML hand-offs, STEP/STL geometry,
rendered notebooks) as an immutable release.

\paragraph{Cross-consumer consistency checks.} Values that must agree
across tool boundaries --- e.g., the CFD case's reference length,
area, and center of rotation versus the fuselage hand-off --- are
cross-checked by tests, so a design move that forgets a consumer fails
loudly. During the case study these checks caught, for example,
propulsion- and vane-CFD geometry that had silently drifted from the
converged design point, which was then re-sourced from the hand-offs
at run time.

A further discipline governs \emph{negative} results: margins that
come out unfavorable are recorded as pinned ``standing findings''
(reported by the final pipeline stage on every run) rather than tuned
away. Section~\ref{sec:results} lists the case study's standing
findings; methodologically, the point is that the AI is instructed to
surface unfavorable physics honestly, and the verification layer
prevents quiet re-tuning.

\subsection{Interaction protocol and provenance}
\label{sec:protocol}

Work proceeds in conversational sessions between an engineer and the
AI agent. The engineer's inputs are \emph{mission-level directives},
not code: representative examples from the case study include
``re-select the airfoil now that the stall-limited sizing is
honest,'' ``adopt a Clark~Y section for the propeller blade and
determine the rotation sense,'' ``fold the battery pack's internal
resistance into the closure consistently,'' and pasted findings from
an external design review. For each directive the agent:

\begin{enumerate}[nosep]
\item locates every discipline the change touches (sizing, geometry,
  control, thermal, CAD, CFD references, documentation);
\item implements the change in the physics library and configuration,
  with rationale comments;
\item re-executes the pipeline and re-converges the design point;
\item updates the regression pins, downstream consumer references, the
  ADR, and the changelog \emph{in the same commit}; and
\item opens a pull request that the human reviews and merges.
\end{enumerate}

Two provenance mechanisms make the AI's role auditable. First, every
AI-implemented commit carries a machine-readable co-authorship trailer
identifying the model, so the exact human/AI contribution split is
recoverable from the git history (Section~\ref{sec:process-results}).
Second, refactoring tasks are verified by \emph{byte-identical output
checks}: when the agent moved all notebook physics into the library
(ADR-0013 in the case study) and later split a pipeline stage
(ADR-0018), the generated hand-offs were verified byte-for-byte
unchanged before and after --- a strong guarantee that a structural
change carried no hidden design change.

The agent also maintains a persistent, human-readable memory of
project decisions and preferences across sessions (e.g., procurement
constraints such as preferring domestic retailers, or the standing
instruction to delete stale generated artifacts), complementing the
constitution with accumulated project context.

\subsection{Evidence-based iteration and external review}
\label{sec:iteration}

The design evolves through short, complete iterations: every
requirement change, model-fidelity improvement, or external finding
triggers a full re-convergence and a tagged snapshot, so the program
history is a sequence of internally consistent design points rather
than a single drifting draft. Three evidence channels feed this loop:

\begin{itemize}[nosep]
\item \textbf{Model refinement}: replacing an assumption with physics
  (e.g., an explicit structural member model replacing an area-density
  estimate; mission-transient battery heating replacing a steady-state
  vent check) and letting the closure re-converge honestly, even when
  the design gets heavier.
\item \textbf{Reality intrusion via procurement}: a deterministic
  commercial-component selection stage derives hard requirements from
  the converged design point and freezes the lightest feasible
  candidates; where no purchasable part matches an assumption (as
  happened with the case study's original fan diameter), the
  assumption --- not the report --- is amended, by ADR, and the design
  re-converged. A subsequent as-selected re-solve stage quantifies the
  gap between the conceptual closure and the frozen hardware without
  contaminating the conceptual baseline.
\item \textbf{Independent expert review}: domain experts outside the
  daily loop review the evolving design; their findings enter as
  directives and are traceable to the resulting ADRs. In the case
  study, external review contributed the semi-monocoque fuselage
  architecture, exposed a stall-speed inconsistency the automated
  checks could not see (a requirement silently unmet because a
  placeholder coefficient survived in one card), and prompted the
  battery internal-resistance accounting fix --- each of which moved
  the design point (Section~\ref{sec:results}).
\end{itemize}

Finally, the conceptual repository hands off to higher-fidelity
consumers through versioned, schema-validated contracts: a JSON
geometry hand-off (planform, body of revolution, control surfaces,
blade stations, moment reference point) feeds an external
vortex-lattice/blade-element analysis loop, while exported CAD and the
OpenFOAM cases support CFD on the same geometry. Schema evolution is
itself governed --- each field addition in the case study was a
reviewed, versioned, backward-compatible schema release, several of
them fixing real consumer-side integration faults (e.g., a missing
wing--body placement anchor that had put wing control points inside
the fuselage in the consumer's solver).

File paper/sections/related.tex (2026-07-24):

\section{AI and Conceptual Design}
\label{sec:related}

This review covers three linked needs: why AI-assisted conceptual
design is needed in aircraft and especially UAV development, which AI
tools and frameworks already exist, and why a tail-sitter VTOL UAV is a
useful validation case relative to other eVTOL architectures.

\subsection{Design need}

Aircraft conceptual design is still constrained by long, costly,
iterative workflows that must reconcile aerodynamics, structures,
propulsion, stability, manufacturing, and mission requirements early,
when most key decisions are fixed
\citep{karali2024surrogate,corrado2022,lukyanov2024}. Conventional
sequential methods depend heavily on designer experience and
low-fidelity semi-empirical models, which are especially weak for UAVs
because many UAV sizes, Reynolds-number regimes, and unconventional
layouts fall outside the historical data behind those regressions
\citep{karali2024surrogate,lukyanov2024}.

UAV design sharpens this need because UAVs can adopt tailless,
blended-wing, morphing, tandem, canard, and other nontraditional
configurations that demand broader design-space exploration and tighter
coupling between mission definition and vehicle architecture
\citep{karali2024surrogate,ivanova2025,lukyanov2024}. High-fidelity CFD
and finite-element analyses improve realism, but thousands of
evaluations across optimization loops make direct early-stage use
computationally prohibitive, motivating automation, surrogates, and
concurrent multidisciplinary design optimization (MDO) workflows
\citep{karali2024surrogate,wang2023,pliakos2025,leng2024}.

\begin{itemize}[nosep]
\item Early MDO detail is needed to reduce late development setbacks
  and resolve the conceptual-stage ``design paradox'' while design
  freedom remains high \citep{corrado2022}.
\item UAV programs need faster iteration because competition, budget
  limits, and expanding mission complexity make broad manual concept
  trades increasingly impractical
  \citep{karali2023,pliakos2025,shakeri2018}.
\item AI is increasingly relevant because modern UAVs already rely on
  autonomy, real-time decision-making, and mission adaptation under
  battery and payload constraints
  \citep{ivanova2025,sai2023,mcenroe2022}.
\end{itemize}

\subsection{AI tools and frameworks}

The literature points to a clear pattern: AI in conceptual aircraft
design is used less as a replacement for physics than as a
computational amplifier around physics-based models, MDO loops, and
design iteration. The dominant tools are surrogate models for
aerodynamics, structural mass, and sometimes radar cross-section;
evolutionary or multiobjective optimizers; automated geometry/CFD
pipelines; and data-mining or multi-fidelity schemes that reduce
coupling and computational burden
\citep{karali2024surrogate,leng2024,pliakos2025}.

Reported frameworks already support configuration selection, early
sizing, and iterative refinement. AI-supported UAV conceptual design
frameworks compare alternative configurations using learned
disciplinary models, feed optimized results back into sizing, and can
cut runtime dramatically; one deep-learning surrogate framework
reported more than three orders of magnitude computational-time
improvement over traditional methods \citep{karali2024surrogate}. The
methodological frontier is widening toward uncertainty-aware MDO,
digital twins, generative AI, and automated data-generation pipelines
that make high-quality training data easier to produce
\citep{karali2024surrogate,wang2023,du2026,pliakos2025}.

Table~\ref{tab:methodclasses} summarizes representative AI-supported
methodology classes reported for aircraft and UAV conceptual design.
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

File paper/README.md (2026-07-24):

# Paper: AI-Assisted Aircraft Conceptualization

LaTeX sources for the manuscript *"AI-Assisted Aircraft
Conceptualization: Preliminary Design of a Tail-Sitter UAV"*
(Tuncer, Güneş, Üçler).

## Build

```bash
latexmk -pdf main.tex          # or: make
```

CI (`.github/workflows/paper.yml`) rebuilds the PDF on every push/PR
touching `paper/` and uploads it as the `paper-pdf` workflow artifact;
tagged releases attach `vbat-paper-<version>.pdf` to the GitHub
Release (`release.yml`).

Requires a standard TeX Live or MiKTeX distribution (pdflatex, natbib,
tikz, booktabs, tabularx — all in the default install). No LaTeX
toolchain was available on the authoring machine, so run the first
build locally and fix any residual typos it flags.

## Layout

- `main.tex` — preamble, title, abstract, acknowledgements
- `sections/` — one file per section
- `references.bib` — bibliography (from the draft's reference list +
  the Claude Code tool citation)
- `figures/` — **copied from the pipeline outputs** (`assets/`,
  `out/`); regenerate there and re-copy after a design change, do not
  edit here
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

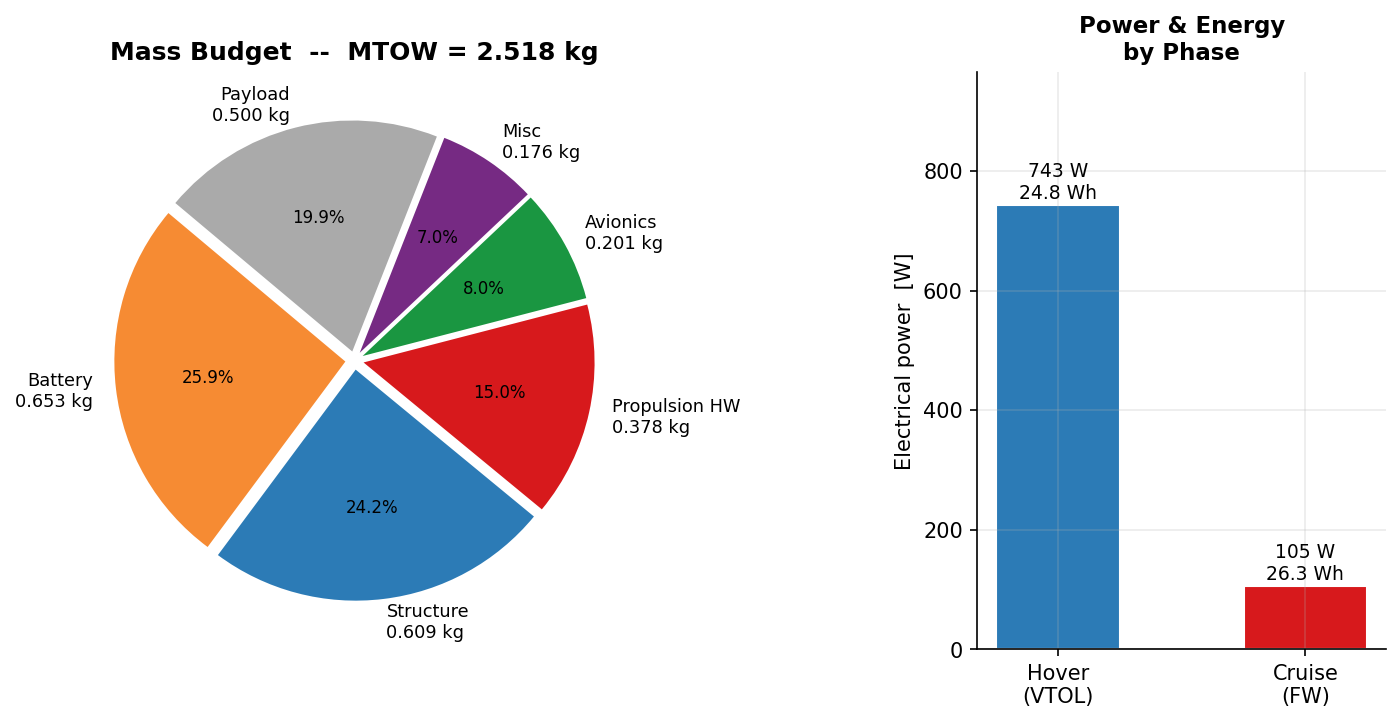
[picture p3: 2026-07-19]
notebooks/figures/design_summary.png

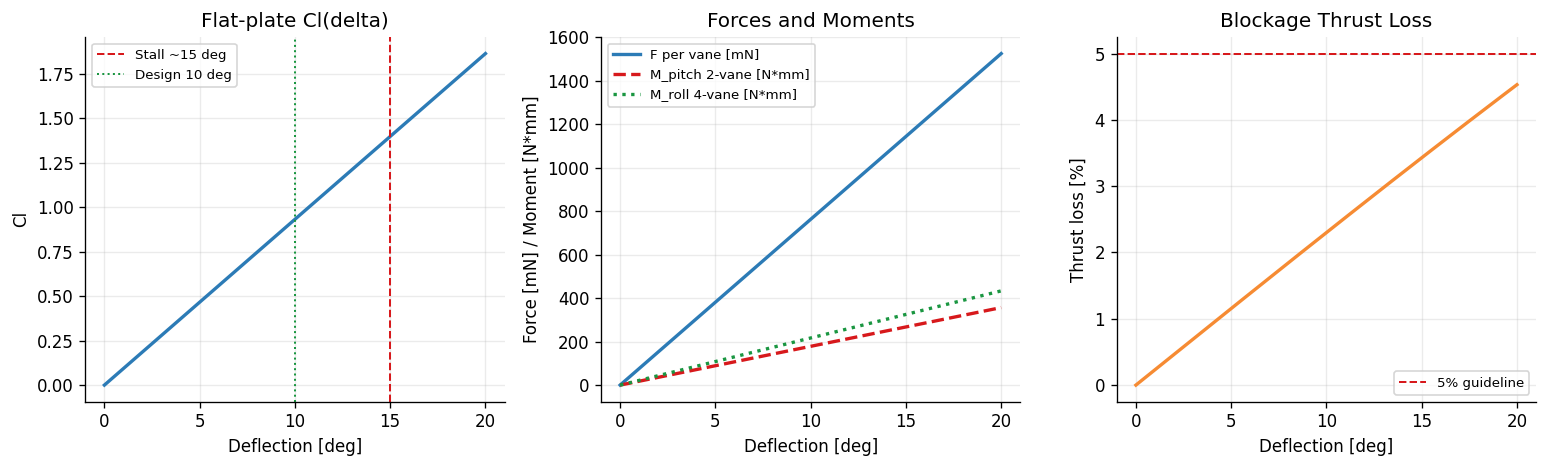
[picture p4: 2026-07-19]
paper/figures/vane_authority_curves.png

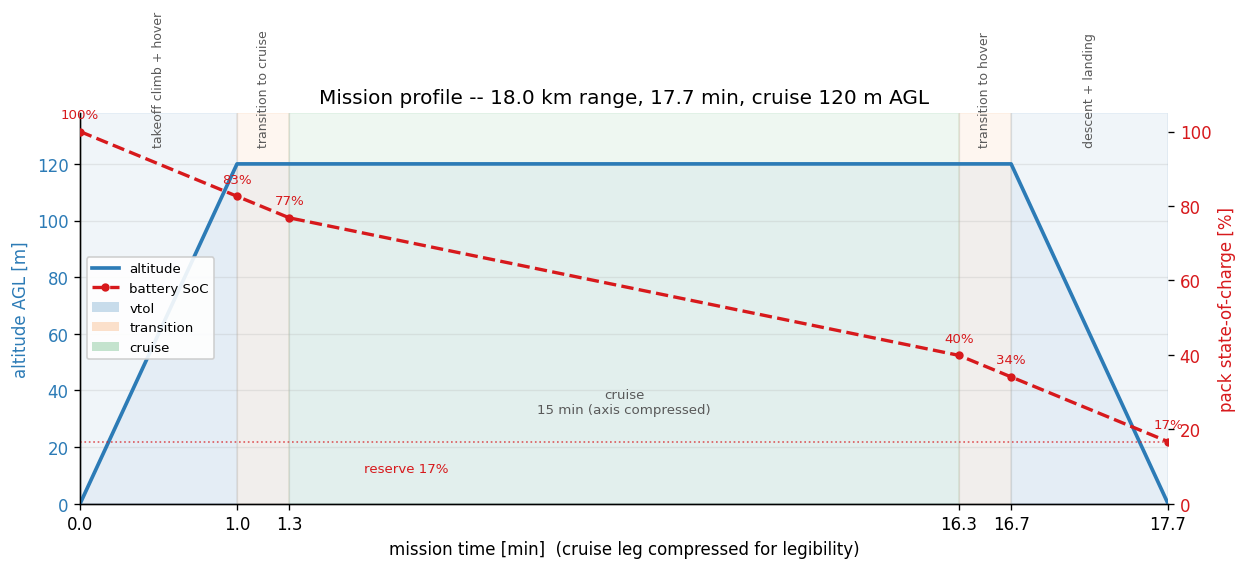
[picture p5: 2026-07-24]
notebooks/figures/design_summary_mission.png

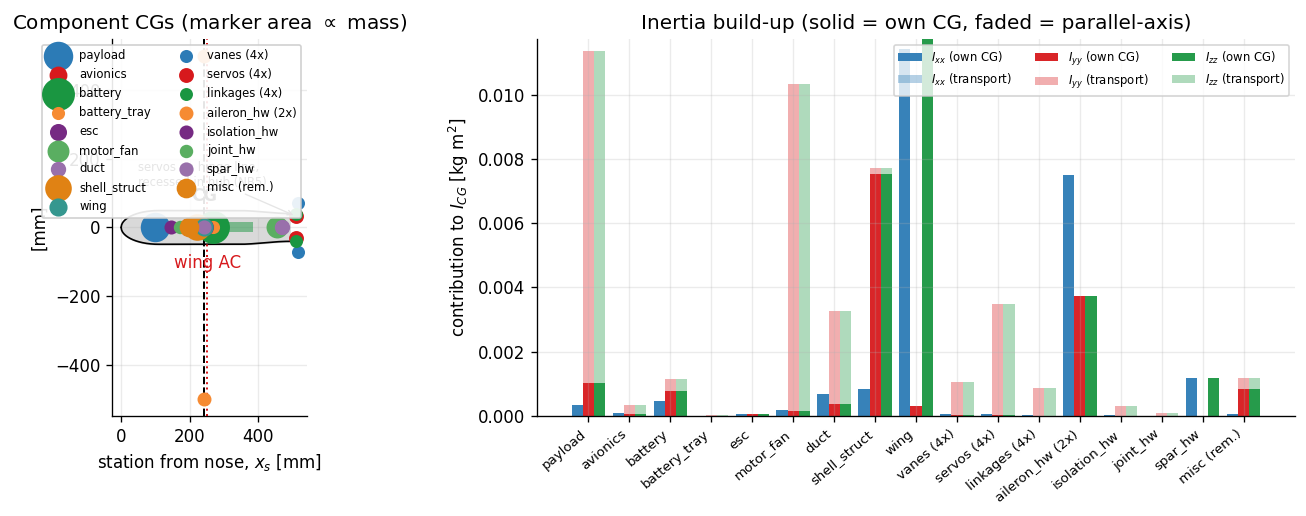
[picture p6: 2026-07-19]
paper/figures/mass_properties.png

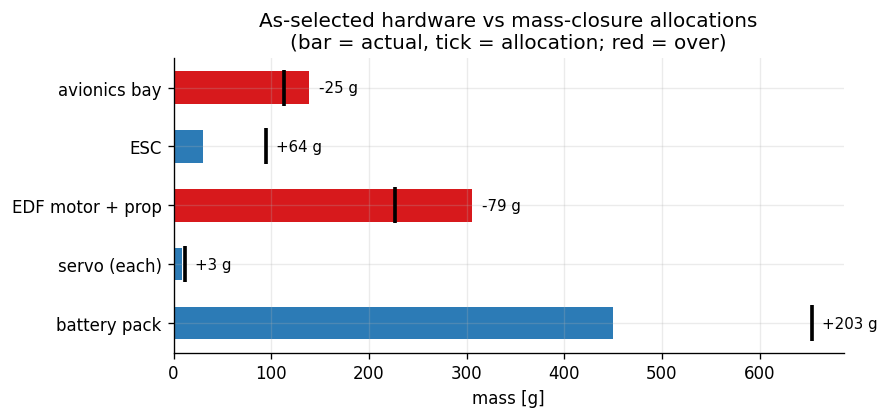
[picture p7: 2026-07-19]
notebooks/figures/design_summary_mass.png

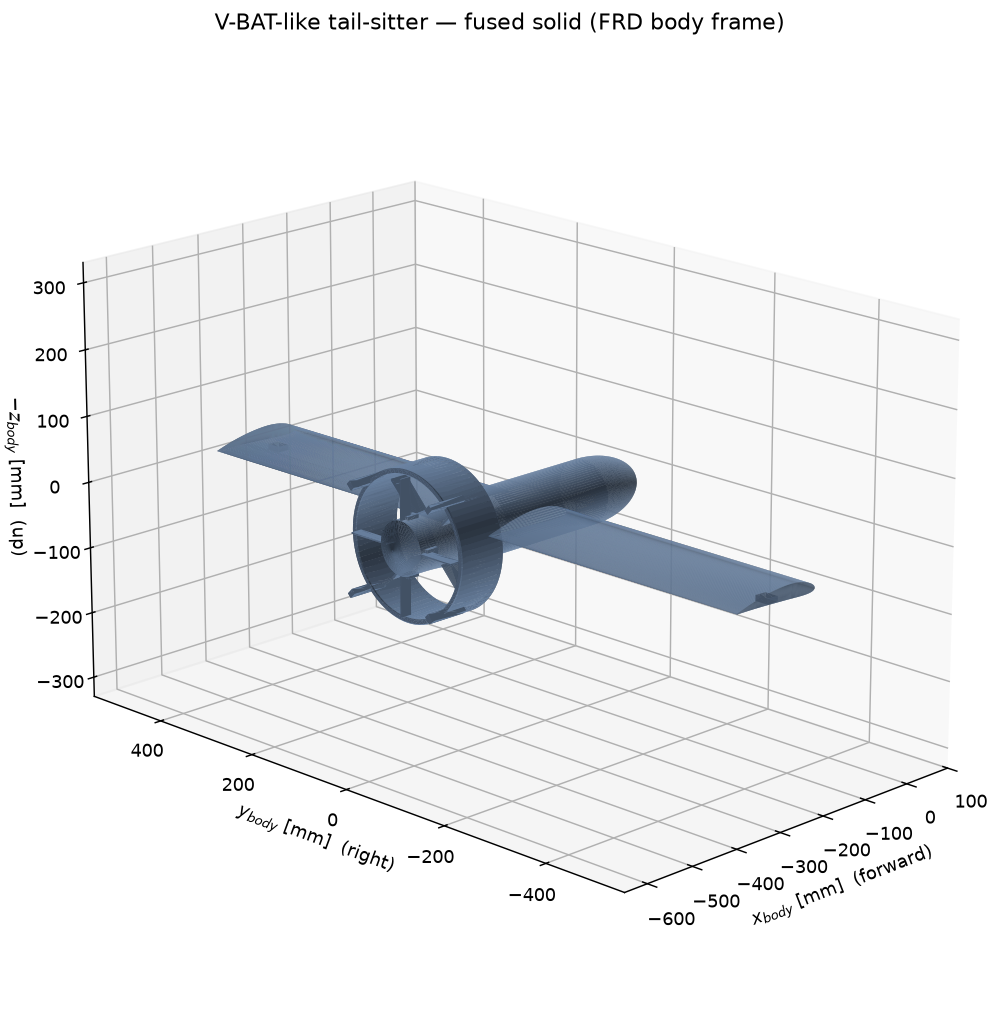
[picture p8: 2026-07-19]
paper/figures/vehicle_iso.png

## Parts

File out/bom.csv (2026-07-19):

part_no | item | qty | material_spec | unit_mass_kg | x_cg_mm | total_mass_kg
VBT-STR-001 | Fuselage semi-monocoque | 1 | segmented_fdm skin + longeron frame + rings (ADR-0010) | 0.3859 | 221.0 | 0.3859
VBT-STR-002 | Wing, constant chord | 1 | CFRP skin/foam core, NACA 4412 | 0.1213 | 242.3 | 0.1213
VBT-PRP-001 | EDF motor + fan rotor | 1 | D = 203 mm EDF, BLDC outrunner | 0.2266 | 454.2 | 0.2266
VBT-PRP-002 | Duct / shroud annulus | 1 | CFRP wound annulus, 8 mm wall | 0.0567 | 467.9 | 0.0567
VBT-PWR-001 | Battery pack | 1 | LiPo, 140 Wh/kg pack-level | 0.6533 | 267.0 | 0.6533
VBT-PWR-002 | ESC | 1 | sized to hover power; incl. inflow-washed cold-plate (NB7) | 0.0944 | 245.5 | 0.0944
VBT-AVI-001 | Avionics stack | 1 | FC + GPS + RX + telemetry | 0.1134 | 193.8 | 0.1134
VBT-PLD-001 | Payload (EO sensor + mount) | 1 | requirement, 0.5 kg | 0.5 | 98.5 | 0.5
VBT-CTL-001 | Jet control vane | 4 | CFRP flat plate 2 mm, c=20.7 mm, h=51.8 mm | 0.003429907488 | 516.3 | 0.013719629952
VBT-CTL-002 | Vane servo, 9g-class | 4 | ~1800 g-cm >= req 483 g-cm, recessed in hub, shaft on hinge line | 0.012 | 511.2 | 0.048
VBT-CTL-003 | Hinge + pushrod set | 4 | pin hinge + wire pushrod per vane | 0.003 | 511.2 | 0.012
VBT-CTL-004 | Aileron servo, 9g-class | 2 | >= req 79 g-cm, on wing at y_arm=500 mm | 0.012 | 242.3 | 0.024
VBT-CTL-005 | Aileron hinge + pushrod set | 2 | pin hinge + wire pushrod per aileron | 0.003 | 242.3 | 0.006
VBT-STR-092 | Vibration isolators | 8 | FC/IMU + payload soft mounts, f_n=56 Hz, 90% 1/rev cut, 0.8 mm sway | 0.004 | 146.1 | 0.032
VBT-STR-093 | Lid hinge strip | 1 | piano hinge along one longeron, lid [0, 344] mm | 0.012 | 171.8 | 0.012
VBT-STR-094 | Lid latches | 1 | 2x quarter-turn on the opposite longeron + reinforcement | 0.008 | 171.8 | 0.008
VBT-STR-095 | Wing carry-through spar | 1 | CFRP tube d8 x 638 mm (computed geometry) | 0.0224 | 242.3 | 0.0224
VBT-STR-096 | Wing root fitting | 2 | printed socket + retention screw per side | 0.006 | 242.3 | 0.012
VBT-STR-091 | Battery tray, adjustable rail | 1 | sliding rail, +/-25 mm travel, trimmed -0.1 mm | 0.015 | 267.0 | 0.015
VBT-STR-090 | Misc: harness, fasteners, bonding, margin | 1 | allocation (remainder) | 0.1613 | 196.4 | 0.1613
VBT-STR-010 | Duct support strut | 4 | flat plate, min 2 mm (in structure) |  | 467.9
VBT-GEA-001 | Landing leg / skid | 4 | on duct, tail-sitter stance (in structure) |  | 516.3

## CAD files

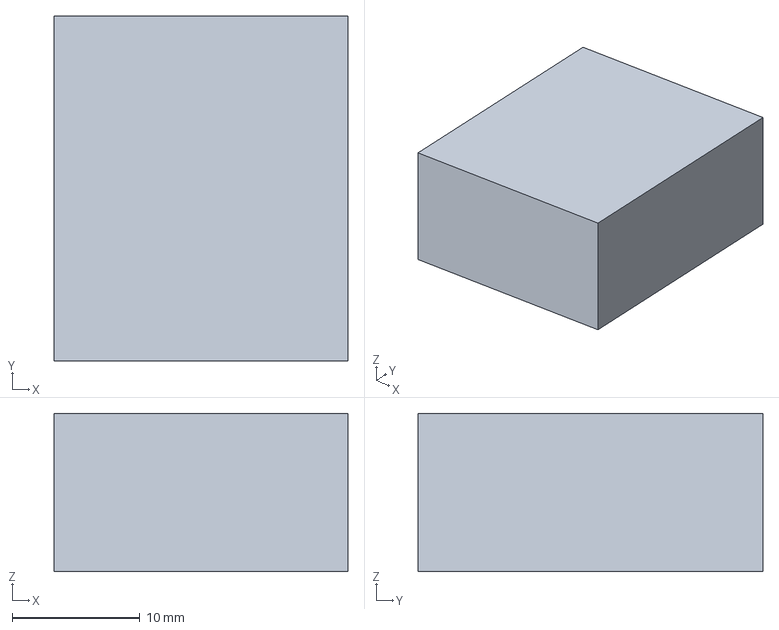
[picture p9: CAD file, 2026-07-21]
out/cad/step/parts/servo_R.step
23.0 x 27.0 x 12.4 mm

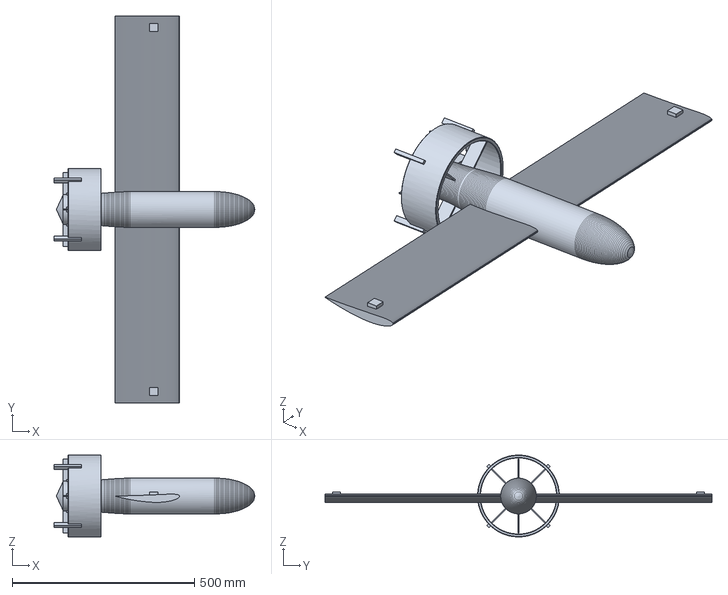
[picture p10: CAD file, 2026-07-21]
out/cad/step/vbat_fused.step
551.7 x 1062.9 x 225.0 mm

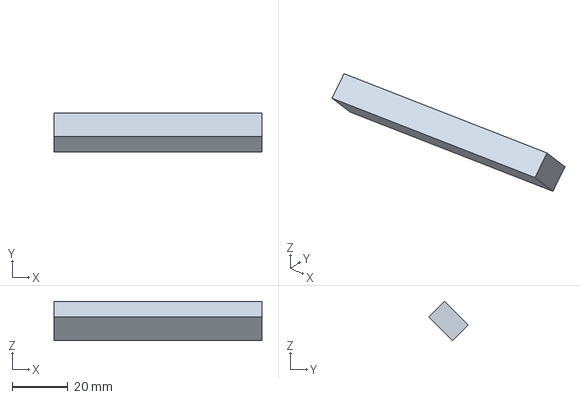
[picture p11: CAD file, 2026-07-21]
out/cad/step/parts/leg_1.step
74.7 x 14.1 x 14.1 mm

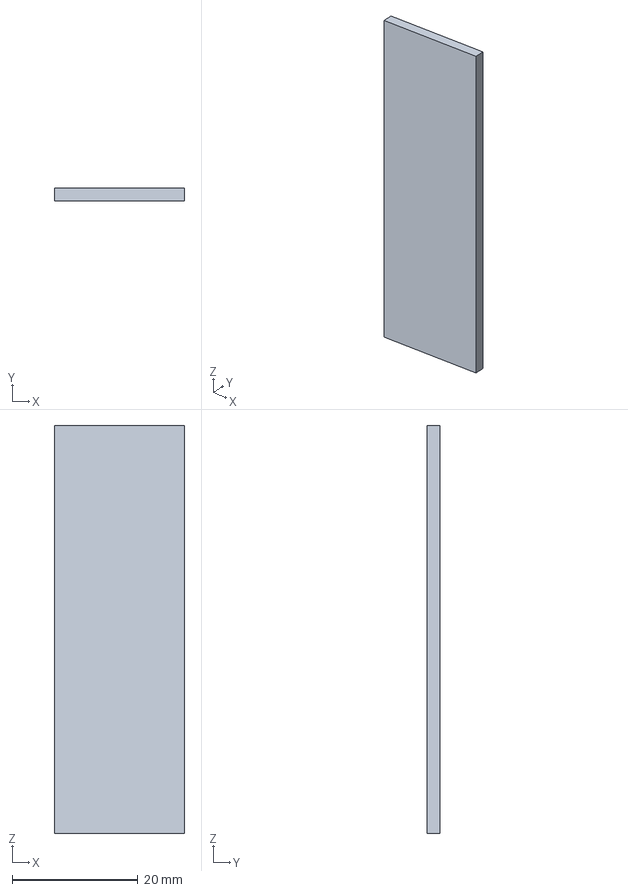
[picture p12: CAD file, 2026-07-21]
out/cad/step/parts/vane_B.step
20.7 x 2.00 x 64.9 mm

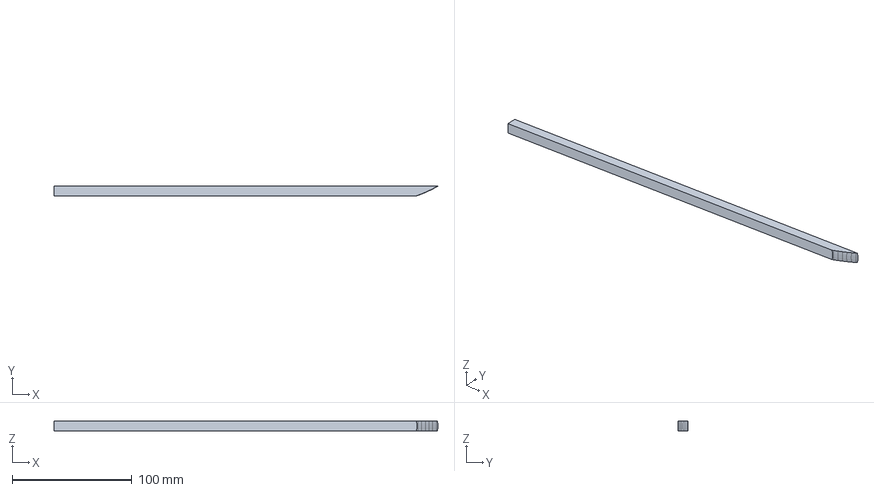
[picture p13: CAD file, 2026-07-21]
out/cad/step/parts/frame_longeron_R.step
320.5 x 8.00 x 8.00 mm

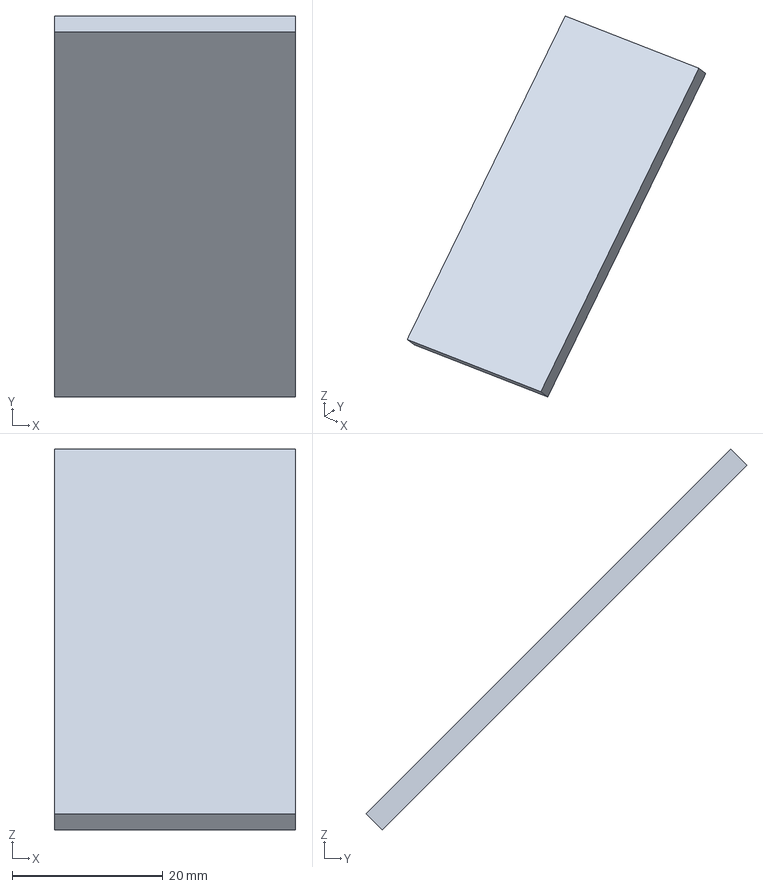
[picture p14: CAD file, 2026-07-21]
out/cad/step/parts/strut_4.step
32.0 x 50.5 x 50.5 mm

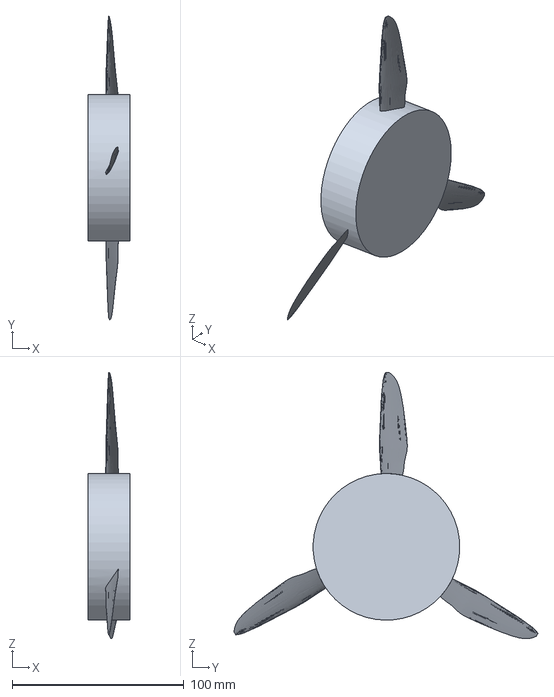
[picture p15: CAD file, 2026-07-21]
out/cad/step/parts/prop_rotor.step
24.4 x 176.8 x 154.9 mm

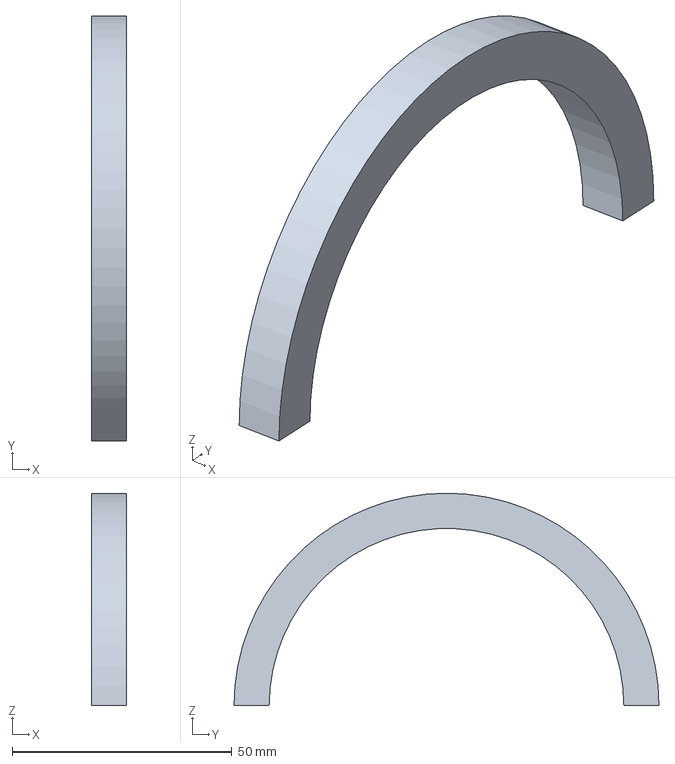
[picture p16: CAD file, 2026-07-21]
out/cad/step/parts/half_ring_2.step
8.00 x 96.6 x 48.3 mm

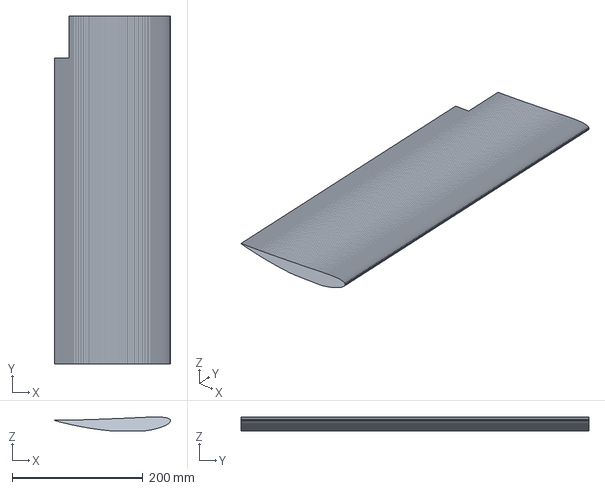
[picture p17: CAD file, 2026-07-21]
out/cad/step/parts/wing_L.step
177.2 x 531.4 x 21.5 mm

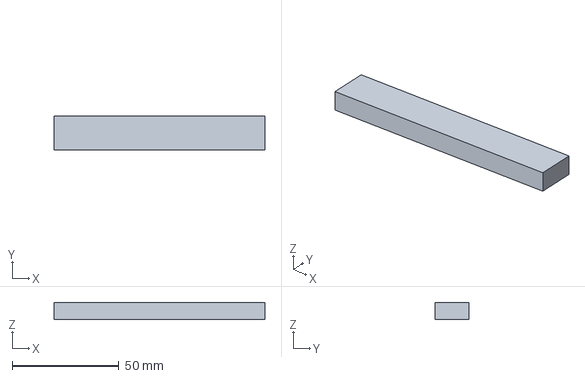
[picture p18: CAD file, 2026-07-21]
out/cad/step/parts/battery_rail.step
99.0 x 16.0 x 8.00 mm

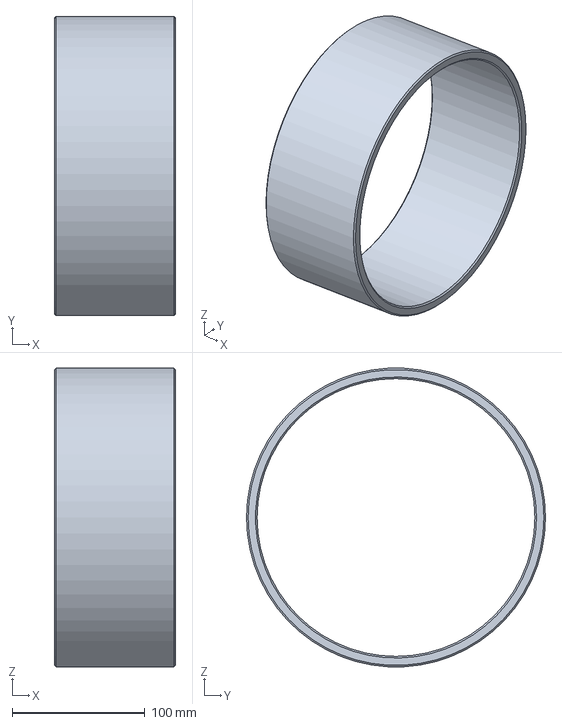
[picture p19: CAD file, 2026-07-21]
out/cad/step/parts/duct.step
91.3 x 225.0 x 224.7 mm

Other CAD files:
out/cad/step/parts/leg_2.step
out/cad/step/parts/servo_B.step
out/cad/step/parts/vane_T.step
out/cad/step/parts/vane_L.step
out/cad/step/parts/leg_4.step
out/cad/step/parts/frame_longeron_L.step
out/cad/step/parts/strut_3.step
out/cad/step/parts/aileron_L.step
out/cad/step/parts/aileron_R.step
out/cad/step/parts/battery_vents.step
out/cad/step/parts/centerbody.step
out/cad/step/parts/crossbeam_1.step
out/cad/step/parts/crossbeam_2.step
out/cad/step/parts/crossbeam_3.step
out/cad/step/parts/esc_cold_plate.step
out/cad/step/parts/fc_imu_tray.step
out/cad/step/parts/fuselage_lid.step
out/cad/step/parts/fuselage_lower.step
out/cad/step/parts/half_ring_1.step
out/cad/step/parts/leg_3.step
out/cad/step/parts/payload_module.step
out/cad/step/parts/servo_L.step
out/cad/step/parts/servo_T.step
out/cad/step/parts/servo_aileron_L.step
out/cad/step/parts/servo_aileron_R.step
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

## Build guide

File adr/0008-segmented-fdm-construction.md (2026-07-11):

# 8. Segmented-FDM construction as the baseline airframe

Status: Accepted (split-line architecture amended by ADR-0010:
the transverse splits -- removable nose, battery hatch -- are
superseded by the longitudinal clamshell; the construction-method
mechanism and the two-piece wing/spar remain in force)

## Context

The airframe was an idealized CFRP monocoque with no split lines: no payload
access, no battery hatch, a one-piece wing. A buildable vehicle needs
modularity — and for a university project, composite tooling is the
bottleneck: every OML iteration means a new mold. The repository already
carries a print-preparation pipeline (`printprep/step2print` segments
oversize parts with alignment pins; `wing_lighten` shells, ribs, and bores a
spar hole) that makes **segmented 3D-printed construction on a CFRP spar
backbone** a realistic alternative: cheaper iteration, worse mass.

The mass cost cannot be bolted on after sizing: the structural fraction sits
inside the mass-closure equation `m_total = (m_payload + m_battery) /
(1 − f_fixed)` and compounds through the battery (heavier → more hover power
→ more battery → heavier). It must re-converge the whole design.

## Decision

1. **Construction method is a first-class config choice**
   (`construction_method` in `config/initial_weight_fraction_estimation.yaml`),
   with a per-method structural-fraction multiplier `k_construction`.
   `WeightFraction.from_yaml` applies `fs = fs_base × k_construction[method]`
   and keeps `fs_base`, `k_construction`, and the method name as fields —
   every notebook re-converges automatically, and the top-down assumption's
   history is never lost (ADR-0005 discipline).

2. **`segmented_fdm` is the baseline** (not a side study). The design point
   re-converges from ~2.5 kg to **~3.06 kg MTOW**.

3. **k = 1.1, deliberately at the low end** of the published 15–30% FDM
   penalty range, paired with a commitment to printprep's mass-discipline
   tooling (shelling, rib lightening, web removal). The closure is
   hypersensitive near its singularity — the sweep that drove this choice:

   | k | MTOW | hover thrust | hover power |
   |---|------|-------------|-------------|
   | 1.00 | 2.50 kg | 32 N | 0.77 kW |
   | 1.10 | 3.06 kg | 39 N | 1.03 kW |
   | 1.15 | 3.53 kg | 45 N | 1.27 kW |
   | 1.20 | 4.57 kg | 58 N | 1.87 kW |

   At the mid-range k=1.2 the vehicle nearly doubles and the hover thrust
   requirement exceeds what a DS-215-class EDF comfortably delivers,
   breaking ADR-0003's COTS constraint. A `T_max_N` guard
   (`config/rotor.yaml`) now fails the sizing loudly if any future change
   pushes the hover requirement past the COTS fan class.

4. **The wing keeps its CFRP-spar Raymer estimate in both methods** — the
   carry-through spar carries wing bending either way; the FDM penalty
   applies to the fuselage/fairing-dominated structural fraction. This is a
   documented approximation, not an oversight.

5. **Three split lines**, geometry and hardware in `config/modularity.yaml`:
   removable nose (payload access, joint ring just aft of the payload bay),
   battery hatch (90° panel over the battery bay), two-piece wing on an
   8 mm CFRP spar tube (matching `wing_lighten --spar-hole 8.0`). Joint
   hardware is discrete named mass carved from the structural pool
   (ADR-0005); spar tube mass is computed from geometry, never configured.
   The CAD splits the fuselage/wing along these exact lines — unions
   reproduce the OML, so the external-aero STL is unchanged in shape and
   the spar tube stays assembly-only (internal, like the prop rotor).

## Consequences

- The whole design point re-baselines (+22% MTOW, +34% hover power):
  every regression pin, `cfd/vehicle/Allrun.case` references, and all
  committed `out/` artifacts change in the same commit — the documented
  "intentional design change" flow.
- Iteration cost drops from mold-rework to overnight reprints; any OML
  change flows `config → CAD → printprep` untouched by hand.
- `k_construction` is the single most sensitive mass parameter in the
  project. Its config comment carries the sweep table; revisit it the
  moment a printed prototype part is weighed.
- Switching back to `monocoque` is one config line; NB1 computes both
  methods side-by-side every run so the trade stays visible.

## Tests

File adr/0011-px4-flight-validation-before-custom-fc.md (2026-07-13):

# 11. Fly on PX4 + COTS Pixhawk before a custom flight controller

Status: Accepted

## Context

The long-term goal includes a custom flight-control card. Designing that
card now would mean guessing its requirements: sensor grades, loop rates,
filtering needs, output channel count, power rails. Every one of those is
measurable by first flying the vehicle on a proven COTS stack — and the
vehicle itself (transition behaviour, vane authority in gusts, hover
power) is unproven, so early flights should not also carry avionics risk.

PX4 is the natural stack: it has a supported **VTOL Tailsitter** type and,
since v1.14, **dynamic control allocation** that accepts a custom actuator
geometry. That matters because this vehicle is non-standard for PX4: a
single EDF with **all hover attitude authority from four jet vanes** — no
differential thrust — plus ailerons as the cruise-phase roll effector
(ADR-0004). No stock airframe matches; a custom actuator configuration is
required either way.

Two vehicle-specific risks shape the plan:

- **Vane effectiveness scales with jet dynamic pressure** (`q_jet` ∝
  thrust). PX4's allocator treats control-surface effectiveness as
  constant, so through transition the vanes' true authority collapses
  while the allocator's model doesn't — exactly the regime where the
  ailerons take over (ADR-0004). This is a tuning risk, not a blocker,
  but it must be characterised in SITL before hardware flies.
- **The built-in simulator cannot be trusted for this vehicle.** Stock
  Gazebo aero plugins are point lift-drag models in the freestream: no
  jet wash on the vanes, no post-stall wing behaviour, no power-on
  duct/airframe interaction — precisely the physics that decide whether
  a tailsitter transition works. Patching a vane plugin into that would
  fix one hole in a model that stays untrustworthy everywhere SITL is
  supposed to de-risk.

The assets for a trustworthy plant already exist: the OpenFOAM vehicle
case (`cfd/`) for the aerodynamics; **Aetherion**
(github.com/onurtuncer/Aetherion), a NASA-checkcase-validated 6-DoF
Featherstone-SVA flight-dynamics library in C++ with a DAVE-ML 2.0
(AIAA S-119) model loader (Janus-derived, CppAD-friendly); and DAVE-ML
itself as the tool-neutral exchange format between the two.

## Decision

1. **First flight is on PX4 running on a COTS Pixhawk-class FC** (Pixhawk
   6C / Cube class), with COTS GPS/compass, digital airspeed sensor,
   telemetry, power module, and an ESC with RPM/current telemetry. The FC
   and sensors live inside the existing avionics budget and on the
   vibration-isolated mount (ADR-0007); no mass-model change.

2. **`px4/` is a new pipeline consumer, downstream of `out/` — exactly
   like `cfd/`** (ADR-0001). It holds the custom airframe/actuator
   configuration and the Gazebo SITL model. Every number in it is copied
   from `config/` or `out/` handoffs and carries a provenance comment
   naming its source, mirroring how `Allrun.case` hardcodes `lRef`/
   `Aref`/`CofR`. Consequently the same discipline applies: **an
   intentional design change must update the `px4/` values in the same
   commit** (a generator script from `out/*.yaml` is the acknowledged
   follow-up once the file set stabilises).

3. **The SITL physics plant is Aetherion driven by CFD-derived DAVE-ML
   models — not Gazebo aero.**
   - The pipeline gains an aero-database leg: parametric OpenFOAM sweeps
     (`cfd/`, production runs on the user's hardware per the CI rule) →
     coefficient/force tables → generated `out/daveml/*.dml`
     (spec: `px4/sitl/daveml_spec.md`), with the same provenance and
     regeneration discipline as every other `out/` artifact, including
     S-119 embedded check-cases so any compliant reader can verify the
     tables round-trip.
   - Aetherion loads them through its `Serialization/DAVEML` readers and
     exposes the plant to PX4 over the simulator-MAVLink **lockstep**
     interface (TCP 4560: `HIL_ACTUATOR_CONTROLS` in;
     `HIL_SENSOR`/`HIL_GPS`/… out). The bridge, sensor models, V-BAT
     plant assembly, and control-law design live in a dedicated
     flight-control repository (planned, unnamed yet) that consumes
     Aetherion as a C++ library — Aetherion itself stays
     vehicle-agnostic, and none of it lives here.
   - The Gazebo model (`px4/sitl/models/`) is **demoted to PX4-side
     integration smoke checks and visualisation**; no flight-dynamics
     conclusion may be drawn from it.

4. **SITL gates hardware.** Order of proof on the Aetherion plant:
   vane-only hover attitude control → hover position hold →
   back-transition → front-transition → cruise with aileron roll. No
   hardware flight before transitions work in SITL.

5. **Staged flight-test campaign**, each stage feeding measured data back
   against notebook predictions: (a) bench — servo signs against the vane
   mixing matrix, thrust stand, IMU vibration survey against the ~211 Hz
   1/rev forcing (`out/vibration.yaml`); (b) tethered/low hover — rate
   tuning, hover power vs the predicted ~710 W; (c) free hover envelope;
   (d) transitions at altitude; (e) cruise — aileron authority vs
   `ddot_min_deg_s2`, cruise current vs prediction.

6. **The custom FC card is specified from flight logs, not estimates.**
   ulog data (sensor PSDs, loop timing, actuator usage, power) becomes
   the requirements document. The custom card's bring-up target is
   **running PX4 itself** (it is designed to be ported) before any custom
   firmware is considered — the card is a hardware project first, not a
   firmware project.

## Consequences

- New top-level `px4/` directory (README, hardware airframe file, SITL
  airframe file, Gazebo model). Like `cfd/`, its scripts run on
  Linux/NuttX — `.gitattributes` forces LF.
- A second set of hardcoded design-point values now exists outside
  `out/`. Until a generator exists, drift is guarded only by the
  provenance comments and commit discipline; adding `px4/` cross-checks
  to `tests/test_design_outputs.py` (as done for `Allrun.case`) is the
  right follow-up once param names are validated against a pinned PX4
  release.
- The trusted-plant decision creates four named work items:
  (a) a parametric CFD sweep runner + post-processing to force/coefficient
  tables (this repo, `cfd/`); (b) a DAVE-ML generator writing
  `out/daveml/*.dml` per `px4/sitl/daveml_spec.md` (this repo, new
  pipeline stage); (c) the dedicated V-BAT flight-control repo — plant
  assembly on Aetherion, PX4 lockstep bridge + sensor models
  (IMU/mag/baro/GPS with noise, optionally the 211 Hz 1/rev line),
  trim/linearization, control-law design; (d) V-BAT trim/response
  check-cases in Aetherion's validation style. Until (a)–(c) exist,
  SITL results carry an asterisk. The flight-control repo consumes
  tagged release snapshots of this repo (never a working tree) and
  seeds the `px4/` gain parameters here, citing its own release tag.
- Aetherion's typed `DAVEMLAeroModel::Inputs` is F-16-shaped (el/ail/rdr);
  the V-BAT model (4 vane deflections + jet state) is driven through the
  generic `evaluateRaw` map interface, or a typed V-BAT policy is added
  Aetherion-side — either way, no change to this repo's handoffs.
- In hover `q_∞ → 0`, so classic coefficient normalisation blows up:
  the airframe table is coefficient-form (valid above a few m/s) while
  the prop/duct and vane models are **dimensional** (N, N·m) functions of
  throttle/jet state — the split is part of the DAVE-ML spec, not an
  implementation detail.
- BEC current budgets and connector choices in `config/electrical.yaml`
  stop being placeholders once the COTS hardware list is frozen —
  expect a config update (and possibly a wiring-diagram regen) at that
  point.
- Flight data may move pinned design values (hover power, vane margins).
  That is the point: measured corrections flow back into `config/` and
  re-converge the pipeline, not into `px4/` locally.

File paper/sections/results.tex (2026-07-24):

\section{Results and Discussion}
\label{sec:results}

The methodology was applied end-to-end to the conceptual design of a
small electric tail-sitter VTOL UAV inspired by early V-BAT-class
demonstrators; the complete design repository --- configuration,
physics library, notebooks, decision records, and full commit history
--- is openly available \citep{tuncer2026vbat}. The configuration
combines a single ducted fan in the aft fuselage, four jet vanes in
the fan efflux providing pitch/yaw/roll authority in hover and
transition, wing ailerons as the cruise-phase roll effector, and
tail-down vertical takeoff and landing. The mission requirement is a
0.5\,kg payload carried through a deliberately short-hover profile ---
120\,s of vertical flight, 40\,s of transitions (billed at hover
power), and 900\,s of cruise at 20\,m/s ($\approx$18\,km range) with a
20\% energy reserve. This section reports (i) the converged design
outcome, (ii) the design-point evolution that produced it, (iii)
process metrics extracted from the project's git history quantifying
the AI's role, and (iv) discussion against the research question.

\subsection{Converged design point}
\label{sec:design-results}

Closure is performed with transparent first-order physics: hover power
from momentum (actuator-disk) theory with an overall figure-of-merit
efficiency chain, cruise power from a conservative lift-to-drag model,
and battery mass from mission energy through pack-level specific
energy, with the pack's Joule losses folded in self-consistently (the
battery efficiency is the mission-averaged $I^2R$ efficiency of the
nominal 90\,m$\Omega$ pack, iterated to the closure fixed point).
Table~\ref{tab:designpoint} summarizes the converged vehicle;
Fig.~\ref{fig:vehicle} shows the parametric solid model regenerated by
the pipeline on every run.

\begin{table}[htbp]
\centering
\caption{Converged conceptual design point (v0.5.2 snapshot).}
\label{tab:designpoint}
\footnotesize
\setlength{\tabcolsep}{4pt}
\begin{tabular}{@{}llll@{}}
\toprule
\textbf{Quantity} & \textbf{Value} & \textbf{Quantity} & \textbf{Value} \\
\midrule
MTOW (closure) & 2.518\,kg & Wing loading & 131.2\,N/m$^2$ \\
All-up mass (as-selected) & 2.336\,kg & Wing area / span & 0.1883\,m$^2$ / 1.063\,m \\
Payload & 0.5\,kg & Aspect ratio & 6.0 \\
Hover electrical power & 743\,W & Airfoil & NACA 4412 ($C_{L,\max,3D}=1.489$) \\
Peak battery discharge & 8.1\,C & Cruise $C_L$ / $L/D$ & 0.535 / 13.35 \\
Rotor & 203\,mm, 3-blade $8\times6$ & Cruise speed & 20\,m/s ($\approx$1.02\,$V_{\mathrm{MD}}$) \\
Blade section / solidity & Clark~Y / $\sigma=0.077$ & Mission & 120\,s hover + 40\,s trans.\ + 900\,s cruise \\
1/rev forcing & $\sim$204\,Hz & Battery (frozen) & Li-ion 6S1P, 108\,Wh, 450\,g \\
Fuselage envelope & $\varnothing$107 $\times$ 533\,mm & Structure & segmented-FDM semi-monocoque \\
\bottomrule
\end{tabular}
\end{table}

\begin{figure}[htbp]
\centering
\begin{subfigure}[t]{0.48\textwidth}
  \centering
  
  \caption{Rendered vehicle, tail-down on its landing legs.}
\end{subfigure}\hfill
\begin{subfigure}[t]{0.48\textwidth}
  \centering
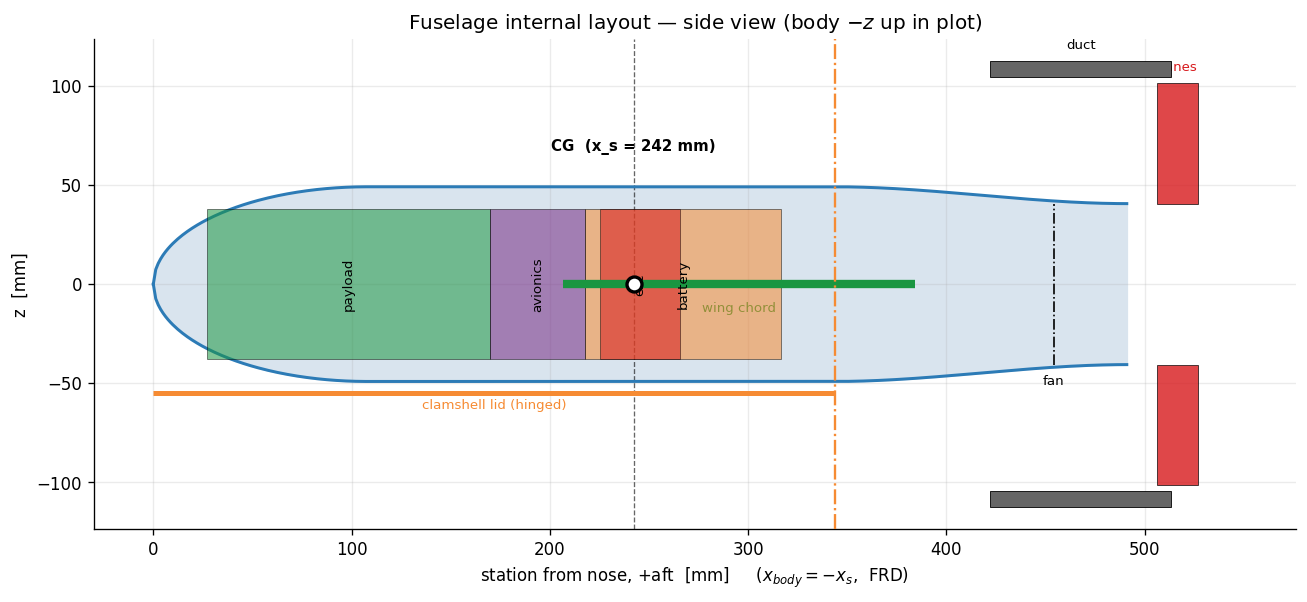
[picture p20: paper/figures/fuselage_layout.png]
  
  \caption{Fuselage packaging and bay stack from the layout stage.}
\end{subfigure}
\caption{Pipeline-generated design artifacts: every figure is
regenerated from configuration by the deterministic pipeline; none is
hand-drawn.}
\label{fig:vehicle}
\end{figure}

The commercial-component freeze (pipeline stage 12) selected, against
requirements \emph{derived} from the converged design point, a
Pixhawk-class PX4 flight controller, a telemetry-capable 80\,A-class
ESC, the pinned 3-blade $8\times6$ propeller, sub-10\,g-class
control-surface servos, and a 21700 Li-ion 6S pack that undercuts the
sized LiPo pack by $\sim$203\,g --- flipping the as-selected all-up
mass 182\,g \emph{below} the conceptual closure. The as-selected
re-solve (stages 13--15) then re-solved the affected subsystems with
real hardware masses and envelopes and confirmed physical fit in the
unchanged $\varnothing$107\,mm hull.

Crucially, the pipeline also reports what does \emph{not} close.
Standing findings pinned at the final snapshot include: a marginal ESC
cold plate (its $\sim$37\,W hover load needs a plate heavier than the
ESC mass allocation, with only a few $^{\circ}$C margin); a battery
pack that, at the 40\,$^{\circ}$C design ambient and nominal
90\,m$\Omega$ resistance, ends the mission $\sim$5\,$^{\circ}$C over
its 60\,$^{\circ}$C limit (making measured pack resistance a
procurement acceptance criterion); and avionics-bay and motor mass
allocations exceeded by $\sim$25\,g and $\sim$79\,g respectively.
These are carried openly as accepted risks with named retirement
paths, not tuned away --- the behavior the standing-findings
discipline of Section~\ref{sec:verification} was designed to produce.

\subsection{Design-point evolution}
\label{sec:evolution}

Table~\ref{tab:evolution} traces the design point across the tagged
snapshots. The trajectory is deliberately non-monotonic: the design
got \emph{heavier} whenever a model was made more honest (the
3D-printability penalty at v0.2.0; the battery internal-resistance
accounting at v0.5.1, $+215$\,g) and lighter whenever architecture or
procurement evidence justified it (the externally reviewed
semi-monocoque re-baseline at v0.4.0; the larger, lower-disk-loading
propeller the component freeze forced at v0.4.1). Each row is a
complete, internally consistent, released design snapshot with its
regression pins, CFD references, CAD exports, and changelog updated in
the same change --- there is no intermediate state in the history in
which the artifacts disagree.

\begin{table}[htbp]
\centering
\caption{Design-point evolution across tagged snapshots. Every row is
a fully re-converged, regression-pinned release.}
\label{tab:evolution}
\small
\begin{tabularx}{\textwidth}{@{}llllX@{}}
\toprule
\textbf{Tag} & \textbf{Date} & \textbf{MTOW} & \textbf{Hover} &
\textbf{Driver of the change} \\
\midrule
v0.1.0 & Jul 09 & 2.50\,kg & $\sim$770\,W &
Initial closure: NACA 2412 wing, 195\,mm COTS fan assumption \\
v0.2.0 & Jul 10 & 3.06\,kg & $\sim$1030\,W &
Honest 3D-printed-structure penalty enters the closure; vibration
isolation and modularity split lines added \\
v0.3.0 & Jul 10 & 3.06\,kg & --- &
Thermal paths sized as structure; marginal ESC cold plate first
reported as a standing finding \\
v0.4.0 & Jul 11 & 2.376\,kg & 710\,W &
Semi-monocoque clamshell fuselage from independent expert review;
structural budget re-baselined to an explicit member model \\
v0.4.1 & Jul 15 & 2.302\,kg & 652\,W &
Component freeze reveals the 195\,mm fan class is unbuyable at this
scale; propulsion decision amended by ADR to a 203\,mm 3-blade
propeller in the airframe duct \\
v0.4.5 & Jul 17 & 2.303\,kg & --- &
Li-ion 21700 pack wins the battery freeze; battery mission-transient
thermal check added from external review \\
v0.5.0 & Jul 17 & 2.303\,kg & --- &
Stall-speed inconsistency found by expert review (placeholder
$C_{L,\max}$ survived in one report); wing re-sized to the real
airfoil limit \\
v0.5.1 & Jul 19 & 2.518\,kg & 743\,W &
NACA 4412 re-selection exploits the now-honest stall constraint;
pack $I^2R$ losses folded into closure ($+215$\,g accepted) \\
v0.5.2 & Jul 21 & 2.518\,kg & 743\,W &
Versioned aerodynamic hand-off contract iterated with the external
solver consumer (six schema releases) \\
\bottomrule
\end{tabularx}
\end{table}

\subsection{Process evidence: quantifying the AI's role}
\label{sec:process-results}

Because every AI-implemented commit carries a machine-readable
co-authorship trailer, the division of labor is recoverable directly
from the git history, providing unusually direct process evidence.

\paragraph{Two phases, one repository.} The project history contains a
natural comparison. In a first, entirely manual phase (4~February --
27~March), 28 commits over seven calendar weeks carried the study
through mission sizing, initial take-off-weight iteration, airfoil
selection, and control-vane design --- roughly the first three of the
eventual sixteen pipeline stages, with physics gradually migrating out
of notebooks. In the AI-assisted phase (4--24~July), 109 commits over
three calendar weeks of part-time work delivered the remaining
thirteen pipeline stages plus the full governance and verification
infrastructure: parametric CAD, CFD cases, vibration, thermal, mass
properties, wiring, component freeze, the as-selected re-solve,
sixteen executed notebooks in CI, 147 pinned regression tests, and
thirteen tagged design releases (v0.1.0 through v0.5.2 in twelve
days). While the two phases are not perfectly controlled (the second
benefited from the first's groundwork), the contrast in scope per
calendar week is roughly an order of magnitude and is consistent with
the acceleration claims in the surrogate-model literature, achieved
here at the workflow level rather than inside a single discipline.

\paragraph{Contribution split.} Of the 109 AI-phase commits, 70
(64\%) carry AI co-authorship trailers; the remainder are human-only
commits (merges, reviews, manual fixes, procurement research). All 23
engineering pull requests of the AI phase were human-reviewed before
merge. The final repository comprises $\sim$11{,}200 lines of
deterministic physics library code, $\sim$1{,}800 lines of tests, 18
commented configuration files, 16 orchestration notebooks, and 18
architecture decision records --- the ADRs and changelog entries
drafted by the agent as part of the changes they document.

\paragraph{Error-catching channels.} The history also documents
\emph{which} safety net caught each class of error, summarized in
Table~\ref{tab:errors}. The pattern is consistent with the layered
design of Section~\ref{sec:method}: automated pins caught silent
drift, schema-governed hand-offs caught cross-tool integration faults,
and independent human expertise caught conceptual errors invisible to
any automated check --- confirming that expert review is a
load-bearing element of the methodology, not a formality.

\begin{table}[htbp]
\centering
\caption{Representative faults during the case study and the
methodology layer that caught each.}
\label{tab:errors}
\small
\begin{tabularx}{\textwidth}{@{}XX@{}}
\toprule
\textbf{Fault} & \textbf{Caught by} \\
\midrule
Propulsion/vane CFD cases silently meshing an obsolete design point &
Cross-consumer consistency discipline; cases re-sourced from hand-offs
with a design-point stamp that refuses stale reuse \\
\addlinespace
Stall requirement silently unmet (placeholder $C_{L,\max}$ vs.\
selected airfoil) & Independent expert review (v0.5.0) \\
\addlinespace
Unrealistically optimistic battery efficiency (implied
$\sim$23\,m$\Omega$ pack) & Expert review prompting the transient
model; closure re-derived from pack physics (v0.4.5--v0.5.1) \\
\addlinespace
Wing control points inside the fuselage in the external solver &
Versioned hand-off schema iteration with the consumer (placement
anchor made mandatory from schema 1.5.0) \\
\addlinespace
Unbuyable propulsion assumption (195\,mm fan class) & Deterministic
component-freeze stage; assumption amended by ADR (v0.4.1) \\
\addlinespace
Refactoring risk while moving physics out of notebooks &
Byte-identical hand-off verification (ADR-0013, ADR-0018) \\
\bottomrule
\end{tabularx}
\end{table}

\subsection{Discussion}
\label{sec:discussion}

\paragraph{Answering the research question.} The case study supports
an affirmative, but conditional, answer to the RQ. The AI accelerated
the program by roughly an order of magnitude in delivered scope per
calendar week --- but the acceleration was \emph{not} obtained by
letting the model produce engineering answers. Every number in
Table~\ref{tab:designpoint} traces to deterministic, configured,
regression-tested physics; the AI's leverage came from (i)
implementing multidisciplinary changes completely, so that a design
move lands with its pins, consumers, decision record, and changelog in
one reviewable diff; (ii) eliminating the bookkeeping latency that
normally separates a design decision from a fully consistent design
state; and (iii) making honest-model refinements cheap enough that
unfavorable results (a $+215$\,g mass growth, a marginal cold plate)
were adopted rather than resisted.

\paragraph{Division of labor.} The observed equilibrium assigns the
AI what LLM agents are reliably good at --- exhaustive propagation,
code implementation, documentation, consistency --- and reserves for
humans what they were uniquely necessary for in this program:
requirement setting, acceptance of every decision, procurement
judgment, and conceptual review. It is notable that both of the case
study's most consequential errors (the stall inconsistency and the
optimistic battery efficiency) were latent \emph{before} the AI phase
and were surfaced during it, one by human expert review and one by an
expert-prompted model refinement the AI then implemented. Neither the
AI alone nor the automation alone would have sufficed; the methodology
is precisely the structure that lets each catch what the other misses.

\paragraph{Generality.} Nothing in
Sections~\ref{sec:pipeline}--\ref{sec:iteration} is specific to
tail-sitters: the constitution, one-way pipeline, pins, ADR
discipline, and interaction protocol transfer directly to any
configuration-driven engineering program with computable analysis
stages. The tail-sitter case exercised the framework hard ---
hover/cruise coupling, dual control effectors, thermal and vibration
constraints, and a procurement reality check all interact --- which is
exactly why it was chosen as the validation vehicle.

\paragraph{Limitations.} The study is a single case with a team
already expert in the domain and the tooling; the phase comparison is
suggestive, not controlled. All analyses are conceptual-level
(momentum theory, lifting-line-class aerodynamics, first-order thermal
and structural models); transition dynamics are energetically budgeted
but not simulated, and no hardware has flown --- the PX4-based flight
validation and the external VLM/BEMT and CFD loops are the designed
next steps, wired into the same hand-off contracts. Finally, the
methodology's guardrails bound, but cannot eliminate, LLM
fallibility: the protection is structural (nothing merges without
passing pins, CI, and human review), and the residual risk
concentrates exactly where automated checks are weakest ---
conceptual assumptions --- which is why independent expert review
remains mandatory in the loop.

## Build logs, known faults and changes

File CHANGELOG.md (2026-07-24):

# Changelog

All notable changes to this conceptual design study are documented here.

The format is based on [Keep a Changelog](https://keepachangelog.com/en/1.1.0/).
Versions are derived from git tags via `setuptools-scm`; never edit a version
by hand. Per project policy, a changelog entry is written whenever a version
is tagged.

## [Unreleased]

### Changed

- **Aeolion handoff moved to its own notebook** (ADR-0018): pipeline is
  now sixteen notebooks — `aeolion_handoff` inserted as NB9,
  `mass_properties` through `design_summary` renumbered NB10–NB16. The
  handoff has no CadQuery dependency and never actually needed the CAD
  build's outputs, so it now regenerates `out/cad/aeolion_geometry.json`
  in the local Python 3.14 venv even when `vehicle_solid_model` (NB8)
  is skipped. `vehicle_solid_model` keeps building/exporting the
  parametric prop rotor and STEP/STL; only the trailing Aeolion-export
  cell moved. Verified byte-identical output (including `design_id`)
  before and after the split.

### Added

- **Aeolion handoff schema 1.8.0** (ADR-0016): new top-level `duct`
  block — the EDF shroud as an annulus of revolution about the body
  x-axis (`inner_diameter`, `outer_diameter`, `chord`) with explicit
  placement (`placement.center`, the mid-chord point on the
  centreline, x = −station like `body`), sourced from the same
  `out/fuselage.yaml` keys the CAD duct solid consumes. Required from
  1.8.0 onward via the established version-conditional pattern; new
  exporter guards (bore must clear the rotor tip, exactly one duct
  layout item). Closes the gap where the vanes' duct-exit eta and the
  prop-in-duct BEMT referenced a duct the contract never described or
  placed.
- **Aeolion handoff schema 1.7.0** (ADR-0017): `propulsion_bemt` gains
  `airfoil_sections` (Clark Y, thickness-scaled per station, CST-fit —
  the same representation as the wing's `airfoil_sections`) and
  `rotation_axis` (a unit vector, right-hand rule, same idiom as
  `hinge_axis`). Both are **required within `propulsion_bemt` from
  1.7.0 onward if the block is present** — `propulsion_bemt` itself
  stays entirely optional at every version; the constraint only bites
  once a document chooses to include it. `rotation_axis` was
  numerically derived, not assumed: for the existing blade twist law,
  a rotation vector along body +x is the only sign giving every
  station a physically sensible (not ~180°) angle of attack.

### Changed

- **Propeller blade section: Clark Y replaces the proprietary
  parametric taper** (ADR-0017): the CAD rotor previously lofted an
  ad-hoc NACA-4-digit-like taper with no published polar data behind
  it. `config/airfoils/clarky.dat` (UIUC Airfoil Coordinates Database,
  verbatim, provenance in the `.dat.source` sidecar) is now the single
  reference section, decomposed into a camber line and a
  half-thickness distribution and thickness-scaled per blade station
  (`config/prop_geometry.yaml`'s `tc_root`/`tc_tip`, reinterpreted as
  scaling targets; `camber_M`/`camber_P` removed). One section law,
  two consumers: `cad/prop_rotor.py`'s loft and the Aeolion
  `propulsion_bemt.airfoil_sections` CST fit. Clark Y was chosen over
  Selig S1223 (single-design-point high-lift, poor fit for a rotor
  that spans hover through cruise) and Eppler E387 (a general
  wing-proven, not propeller-proven, section) for its track record in
  classical propeller BEMT validation literature. `out/cad/` blade
  cross-sections change shape; no design-point (MTOW/hover power/wing)
  change.

### Fixed

- **Aeolion handoff schema 1.6.0**: no moment reference point existed
  in the contract, so a VLM/BEMT sweep's Cm/Cl/Cn had no stated
  centre and defaulted to the coordinate-system origin — not
  physically meaningful for a body whose CG sits well aft of the
  nose. New top-level `moment_reference_point` {x, y, z}, sourced
  from the SAME place `cfd/vehicle/Allrun.case`'s `CofR` is
  (`out/fuselage.yaml` `x_CG_m`), so VLM/BEMT moments stay directly
  comparable to the project's CFD force/moment coefficients.
  **Required from 1.6.0 onward** via the same version-conditional
  schema constraint used for `planform.placement`: 1.0.0–1.5.0
  documents remain structurally valid without it. New exporter guard:
  `0 < x_CG_m < L_fus_m`.

## [0.5.2] — 2026-07-21

Patch release: five Aeolion handoff schema bumps (1.1.0 → 1.5.0),
landed as separate reviewable PRs over three days — jet-vane control
surfaces, wing/duct-jet lattice binding, the fuselage body of
revolution, BEMT blade count, control-surface deflection ranges, and
finally the wing/body placement anchor that fixed a real solver-side
overlap bug. No VBAT design-point change; schema/exporter only.

### Fixed

- **Aeolion handoff schema 1.5.0**: the planform had no stated
  position relative to `body` — both implicitly started at the
  reference-frame origin, so a consumer placed the wing root at the
  fuselage nose (22/384 wing control points landed inside the body of
  revolution in an Aeolion solver report). New `planform.placement.
  root_leading_edge` anchor {x, y, z} in the same body-frame
  convention as `body`, sourced from `x_wing_LE_m`: `[-x_wing_LE_m, 0,
  0]` — the wing sits on the fuselage centerline (a through-fuselage
  wing on the carry-through spar). **Required from 1.5.0 onward** via
  a version-conditional schema constraint (not merely documented as
  optional-but-always-present, unlike prior additions): 1.0.0–1.4.0
  documents remain structurally valid without it, every 1.5.0+
  document must carry it. New exporter guard: `0 < x_wing_LE_m <
  L_fus_m`.

### Added

- **Aeolion handoff schema 1.4.0**: `control_surfaces` entries carry
  `deflection_limits_deg` (`min`/`max`, the symmetric mechanical range
  about `hinge_axis` from `±delta_max_deg`) so a CFD/VLM deflection
  sweep stays within the physical actuator/plate range. Vane entries
  additionally carry `deflection_soft_limit_deg` (the flat-plate
  stall onset, informational). 1.0.0–1.3.0 documents remain valid.

### Fixed

- **Aeolion handoff schema 1.3.0**: `propulsion_bemt.n_blades` was
  missing — BEMT solidity/thrust are per-blade quantities scaled by
  count, and `blade_stations` alone only describes one blade's
  chord/twist law. Added from the same `prop_geometry.PropGeometry`
  the blade stations sample; 1.0.0–1.2.0 documents remain valid.

### Changed

- **Aeolion handoff schema 1.2.0**: optional `body` block — the
  fuselage as a body of revolution ({x, radius} stations sampled from
  the same 3-segment meridian the CAD revolve uses, cosine-spaced at
  the fixed `n_body_stations` count, body x = −station in
  `aetherion_body_frd`). Never bound to a lifting lattice; intended
  for slender-body/Munk trim corrections and duct-jet context. 1.0.0
  and 1.1.0 documents remain valid; the exporter stamps 1.2.0.
- **Aeolion handoff schema 1.1.0** (from the Aeolion-side integration
  review): `control_surfaces` entries carry an explicit `surface`
  binding — `wing` (eta = semispan fraction) or `duct_jet` (all-moving
  plate in the jet, eta = duct-exit radius fraction, never bound to a
  lifting-surface lattice) — removing the ambiguity of the wing aileron
  and the four cruciform vanes sharing one planform's eta space. The
  field is optional in the schema so 1.0.0 documents stay valid (bind
  by `name` when absent); the exporter always emits it and stamps
  `schema_version: 1.1.0`. ADR-0016 updated with the binding
  convention and the consumer-side frame-conversion note.

## [0.5.1] — 2026-07-19

Patch release: the NACA 4412 wing re-selection, the ADR-0014 amendment
folding the pack's internal resistance into the closure honestly
(design point moves to **2.518 kg MTOW / 743 W hover**), and the
versioned Aeolion geometry handoff (ADR-0016) — the parametric contract
for the external VLM/BEMT adjoint loop, jet vanes included.

### Added

- **Aeolion geometry handoff** (ADR-0016): NB8 exports
  `out/cad/aeolion_geometry.json` beside the STEP files, conforming to
  the Aeolion-side pinned 1.0.0 JSON Schema
  (`schemas/vbat-aeolion-geometry-handoff.schema.json`, 2020-12,
  `additionalProperties: false`, stored verbatim and validated in
  tests): planform stations + Kulfan CST airfoil sections aligned 1:1
  by eta at fixed counts (`config/aeolion.yaml` — structural constants
  of the optimization, not design variables), control surfaces (the
  aileron plus the four jet vanes as all-moving plates on the duct-exit
  radius with radial hinge axes), BEMT blade stations, static mesh topology,
  and a `design_id` sha256 of the canonical payload (byte-stable per
  design point). JSON is the differentiable-analysis contract; STEP
  stays the exact-CAD traceability artifact, off the derivative path.
  New CadQuery-free `prop_geometry.py` is the single source of truth
  for the blade chord/twist laws, shared by the CAD rotor and the BEMT
  handoff.

### Changed

- **Battery internal-resistance accounting made consistent (ADR-0014
  amendment)**: `eta_bat` 0.97 → 0.916, the mission-averaged I²R
  efficiency of the nominal 90 mΩ pack iterated to the closure fixed
  point (the old 0.97 implied an unrealistic ~23 mΩ pack), and the
  battery-bay vent load now uses the same I²R law as the mission
  transient. The honest accounting costs **+215 g: MTOW 2.303 →
  2.518 kg** (hover 743 W, 8.1C peak; wing S 0.1883 m², b 1.063 m).
  Standing findings move with it: the nominal-pack mission transient
  worsens to ~65 °C vs the 60 °C limit, ESC cold-plate load rises to
  ~37 W (still marginal), the margined ESC current requirement rises to
  ~54 A (still within the APD 80F3[x]), the frozen 450 g Molicel pack
  now undercuts the sized pack by ~203 g (as-selected all-up 2.336 kg =
  closure −182 g) — and the ADR-0012 structure-over-budget finding is
  **resolved** (the larger structural pool covers the packaging-floored
  shell with ~9 g margin). Measured pack DCIR at procurement remains the
  lever: a 60–70 mΩ build claws most of the mass back. Pins,
  `Allrun.case`, and all `out/` artifacts updated in the same change.
- **NACA 4412 wing** (ADR-0015): airfoil re-selected 2412 → 4412 after
  the v0.5.0 stall-consistency fix made section lift buy wing area
  directly. W/S 107.2 → 131.2 N/m², S 0.2107 → 0.1722 m², b 1.124 →
  1.016 m (smaller than the pre-fix wing), MAC 0.187 → 0.169 m, cruise
  CL 0.535 near the polar optimum, L/D 12.76 → 13.35, V_MD ≈ 18.5 m/s
  so the 20 m/s cruise is within ~2% of max L/D. A V_cruise change was
  studied (16–22 m/s through the closure) and rejected: the fixed-range
  mission energy is nearly V-independent under the configured constant
  L/D. MTOW / hover power / battery point unchanged. Watch items
  (ADR-0015): un-modelled 4412 nose-down Cm0 (cruise trim) and the
  empirical Cl_max at Re ≈ 1.4e5 near stall. Pins, `Allrun.case`, and
  CAD updated in the same change.

## [0.5.0] — 2026-07-17

Minor release: the wing is re-sized to the selected airfoil's real
CL_max — a design-point change (wing geometry, MAC, CFD references),
hence the minor bump. Ships on top of the v0.4.5 content (Li-ion
freeze, thin notebooks, pack-transient check), now merged to main
(PR #18).

### Fixed

- **Stall-speed consistency** (from the 2026-07 external aero review by
  C. Ucler): the wing card's 11.98 m/s stall line was computed from the
  pre-selection placeholder `CL_max: 1.4` while every other number on
  the card came from the selected NACA 2412 (`CL_max_3D = 1.2186`) —
  the real wing stalled at ~12.8 m/s and the V_stall ≤ 12 m/s
  requirement was silently unmet. `CL_max` is now the selected wing's
  1.2186 (and must track the NB2 selection). The stall-limited wing
  loading drops 123.2 → 107.2 N/m² (S 0.1834 → 0.2107 m², b 1.049 →
  1.124 m, MAC 0.175 → 0.187 m, cruise L/D 13.22 → 12.76); MTOW,
  hover power, and the battery point are unchanged. Regression pins,
  `Allrun.case` (lRef/Aref/CofR), and the CAD exports updated in the
  same change.

## [0.4.5] — 2026-07-17

Patch release: Li-ion battery freeze, thin-notebook refactor, and the
battery pack mission-transient thermal check from the external design
review.

### Added

- **Battery pack mission-transient thermal check** (ADR-0014, from the
  external battery-thermal review by C. Ucler): NB7 now integrates the
  pack's own `I²R_pack` Joule heat through the two vertical legs
  (adiabatic) with laminar flat-plate cruise cooling between, at the
  wiring-law currents and configured 60/90/120 mΩ pack-resistance
  cases. New `battery_transient` block in `out/thermal.yaml`; margins
  row and standing finding in `design_summary`; regression pins. New
  standing finding: at the 40 °C hot-day ambient the nominal 90 mΩ
  pack ends the mission at 62.4 °C average vs the 60 °C limit — the
  optimistic 60 mΩ build passes (54.9 °C), making measured pack DCIR
  the procurement acceptance criterion. `eta_bat: 0.97` is unchanged
  in the closure but documented as implying an unrealistic ~23 mΩ
  pack.
- **Molicel P50B 6S1P 5000 mAh Li-ion (21700)** added to the battery
  catalog and won the freeze at 450 g — ~105 g under the sized LiPo
  (pack-level specific energy beats the configured LiPo density). The
  battery budget line flips positive and the as-selected all-up drops
  to 2.264 kg (−38 g **under** the closure MTOW, from +125 g over in
  v0.4.4). Note its 3.6 V/cell nominal vs the configured 3.7.

### Changed

- **Thin-notebook refactor** (ADR-0013): all physics, figure, and
  report code moved from the notebooks into `src/conceptual_design/`
  (`design_point.py` as the single sizing-loop call site, `plots/`,
  `reports.py`, `design_summary.py`, `notebook.py` shared prelude).
  Notebooks are now parameters + module calls + interpretation only;
  the `out/` handoffs were verified byte-identical across the move.
  NB8 (`vehicle_solid_model`) keeps its inline sizing block (CI-only).

## [0.4.4] — 2026-07-17

Patch release: post-freeze as-selected re-solve stage (ADR-0012) — the
pipeline is now fifteen notebooks.

### Added

- **NB12–NB14 as-selected re-solves** (`aileron_design_cots`,
  `vibration_isolation_cots`, `fuselage_design_cots`): NB4–NB6 re-solved
  downstream of the COTS freeze with the frozen hardware — real servo/FC
  masses, pack density from the battery's own envelope, bay lengths
  floored at each rigid part's best-orientation axial length, actual
  motor/prop/ESC layout masses, and a physical-fit report. Parallel
  `out/*_cots.yaml` handoffs; the conceptual solutions and the CAD/CFD
  geometry are untouched (no back-edge). New standing findings, pinned:
  as-selected all-up 2.427 kg (+125 g over the 2.303 kg closure),
  as-selected hull ⌀106 × 531 mm, structure model ~33 g over budget.
- **NB15 `design_summary`** (last notebook): pure reader — design point,
  margins table, frozen COTS hardware, and all standing findings
  collected programmatically from the `out/` handoffs.
- `src/conceptual_design/cots_integration.py` and backward-compatible
  `fuselage_design.py` extensions (`min_axial_length_m`,
  `part_envelopes`, `prop_item_masses`); `part_clearance_m` in
  `config/fuselage.yaml`; regression pins for the new handoffs;
  ADR-0012.

## [0.4.3] — 2026-07-15

Patch release: frame-longeron display parts no longer protrude through
the nose taper.

### Fixed

- **Frame longerons trimmed to the hull**: the L/R clamshell-joint
  longerons were straight bars at y = ±0.35 D running the full
  clamshell length to the nose tip, so forward of ~station 22 mm they
  protruded through the nose taper. `frame_parts` now intersects them
  with the fuselage solid — they end where the ogive becomes narrower
  than the joint line (display part only; the member mass model is
  unchanged).

## [0.4.2] — 2026-07-15

Patch release: the v0.4.1 snapshot shipped with the prop rotor CAD still
carrying EDF-cartridge proportions at the EDF-era station; this release
rebuilds it as the actual COTS 3-blade prop-in-duct.

### Fixed

- **Prop rotor CAD rebuilt to the actual COTS 3-blade prop** — the v0.4.1
  snapshot still carried EDF-cartridge proportions and the EDF-era
  station: a 114 mm hub barrel + spinner (hub_length_ratio 0.35,
  spinner_ratio 1.0) placed at the duct CG, which buried the hub inside
  the fuselage tailcone, pushed the spinner out through its skin, and
  had the blade roots emerging through the tailcone (the tailcone is
  still ~83 mm across at that station). The rotor is now a short
  adapter collar (~24 mm, no spinner) with the disk plane at the
  fuselage-tailcone / exhaust-centerbody junction (`L_fus_m`), where
  the body has shrunk to the 40.6 mm centerbody radius and the blades
  clear the airframe. Blade planform replaced by a peaked chord law
  (`c_peak_ratio`/`f_peak`, max chord at 35% span) with a rounded tip
  (`tip_round_expo`), matching the COTS 8x6 look while keeping the
  ~14-15 mm mean chord of the sigma = 0.077 solidity model. Diameter
  stays exactly 203 mm and the twist stays the exact
  constant-geometric-pitch law beta(r) = atan(p/2*pi*r) with the true
  6 in pitch. NB8's rotor-diameter printout fixed for 3 blades (bbox
  z-max, not z-extent).

## [0.4.1] — 2026-07-15

Point release on the ADR-0010 baseline: freezes the open COTS hardware
(NB11), amends ADR-0003 to the 3-blade 203 mm prop-in-duct the selection
forced — re-converging the design to **MTOW 2.302 kg / 652 W hover** —
and drift-proofs the propulsion/vane CFD cases against future design
moves.

### Added

- **README hero render** (`assets/vbat_render.png`): shaded 3D view of the
  vehicle standing tail-down, rasterised straight from the exported part
  STLs by `scripts/render_readme_cad.py` (self-contained numpy/Pillow
  z-buffer renderer — no OpenGL needed); linked to the interactive Pages
  viewer from the top of the README.
- **COTS component selection & freeze** (new pipeline stage
  `cots_selection`, NB11): selects the open COTS hardware — flight
  controller, ESC, EDF drive motor, propeller/fan unit, vane/aileron
  servo — from a per-category candidate database
  (`config/components/*.yaml`) against requirements **derived** from the
  converged design point (ESC current via the wiring-module law, motor/fan
  power from `P_design`, rotor diameter from `config/rotor.yaml`, servo
  torque from the NB3/NB4 hinge moments; only the margins are configured).
  Lightest feasible candidate wins deterministically; a `selection.frozen`
  id pins a procured part and is re-validated every run, failing loudly if
  a design change outgrows it. Freezes ids, masses, and own-CG inertia
  tensors to `out/components.yaml`, pinned by new design-regression tests.
  Selected stack: Pixhawk 6C, APD 80F3[X] (ADR-0011's telemetry
  requirement eliminates the Hobbywing/T-Motor field), SunnySky
  X4120-class motor, DS-215-DIA HST fan, KST X08 servos.
- **Finding (dominant): the ADR-0003 "COTS 195 mm EDF" class has no
  light implementation.** The only COTS fan at the frozen diameter is the
  Schübeler DS-215 heavy-lift family; fan + lightest plausible motor land
  ~6× over the propulsion allocation (−1069 g). A COTS 3-blade prop in
  the airframe duct (V-BAT-like) is ~40× lighter but exists at
  178/203 mm, not 195 mm — kept visible as a diameter-only rejection
  because adopting it means moving `D_rotor_m`, re-converging, and
  amending ADR-0003. Second finding: the lightest PX4 stack overruns the
  avionics bay by ~37 g. Both pinned as standing findings (ADR-0009
  discipline).

- **Battery pack joins the COTS selection** (`batteries.yaml`): fully
  derived requirements (6S exact, capacity ≥ the sized mission Ah,
  continuous discharge ≥ the ESC's margined hover current — no
  configurable margin), compared against the mass-closure battery mass
  where COTS capacity quantisation makes a small overshoot expected
  (Gens Ace 6S 4000 30C: ~58 g over the sized pack). Candidates across
  all categories now carry procurement URLs preferring Turkish
  retailers; the forced imports are the telemetry ESC (no TR retailer
  stocks a live-telemetry 50 A+ single ESC) and the KST X08 servo
  (TR fallback: MG90S, +3 g each).

### Changed

- **ADR-0003 amended: the COTS rotor is a 3-blade 8×6 propeller
  (203 mm) in the airframe duct, replacing the 195 mm COTS EDF
  cartridge** — resolving NB11's dominant finding (the only purchasable
  195 mm fan is 10 kW-class heavy-lift hardware). The sizing physics
  already modelled a low-solidity prop (σ = 0.077 matches a 3-blade 8×6
  over the annulus outside the 0.4 R hub); only the procurement
  assumption changed. `D_rotor_m` 0.195 → 0.203 and the whole design
  re-converged: **MTOW 2.376 → 2.302 kg, hover 710 → 652 W** (+8% disk
  area, lower disk loading), 1/rev forcing 211 → 204 Hz, pack 3.71 →
  3.50 Ah. `T_max_N` guard re-derived for the prop-in-duct power
  ceiling (50 → 35 N — note hover now sits at ~84% of the guard;
  thrust-stand verification is ADR-0011 stage a). The CAD rotor is now
  a 3-blade prop (`config/prop_geometry.yaml`). All regression pins,
  `cfd/vehicle/Allrun.case`, and the `px4/` provenance values
  (airframe params, Gazebo model, README) updated in the same commit;
  `out/cad/` regenerates in CI. Propulsion mass now closes to a ~100 g
  finding (all motor, EST) instead of ~1.1 kg of unbuyable hardware;
  NB11 pins the propeller via `selection.frozen` (the TR-stocked
  2-blade Gemfan is lighter but re-opens the solidity/FoM revisit).
- **Trusted SITL plant redirected to Aetherion + CFD-derived DAVE-ML**
  (amends the v0.4.0 PX4 plan): the trusted plant is **Aetherion**
  (external 6-DoF repo) consuming **DAVE-ML models generated from CFD
  results** (`px4/sitl/daveml_spec.md`: coefficient-form airframe +
  dimensional prop/vane models to survive the hover `q_∞ → 0`
  singularity, S-119 check-cases, validation gates); the Gazebo model is
  demoted to PX4-side integration smoke checks.

### Fixed

- **Prop/vane CFD geometry sourced from the design handoffs, not
  hardcodes** (`cfd/prop/make_geom.py`, `Allrun.prop`, `Allrun.vanes`,
  `foam2dml_prop.py`): the actuator-disk propulsion case still built the
  ancient 286/302 mm duct (56 mm hub) and the vane sweep still meshed
  the pre-resize vane (span 0.0714 m, chord 0.02856 m, V_jet
  23.38 m/s) — both had silently drifted from the converged design
  point. The duct/hub dims now come from `out/fuselage.yaml` and the
  vane dims/default jet speed from `out/control_vanes.yaml` at run
  time; `Allrun.prop` refuses to reuse a base mesh built for a
  different design point (`base/.geom_dims` stamp), and the DAVE-ML
  exporter builds its provenance text from `run_meta.yaml`, exiting
  loudly on sweeps that predate the change. `Allrun.vanes` also gains
  the previously missing `constant/transportProperties` and
  `turbulenceProperties`, without which simpleFoam could not run at
  all.

## [0.4.0] — 2026-07-11

Fourth design snapshot: the semi-monocoque clamshell architecture from
Çağlar Uçler's external design review, and the budget re-baseline it
justified — **MTOW 3.06 → 2.376 kg**, lighter than the original 2.5 kg
monocoque baseline. Also lays the PX4 flight-validation groundwork
(ADR-0011): fly on a COTS Pixhawk before designing the custom FC card.

### Added

- **Semi-monocoque clamshell fuselage** (ADR-0010, from Çağlar Uçler's
  external design review): the fuselage becomes a longitudinal clamshell —
  structural lower half + full-length hinged upper lid — with a rectangular
  profile around the joint line working as the longerons, crossbeam
  equipment mounts, and 2 half-rings tying the lower-centerline battery
  rail to the frame. An explicit member model (skin + longerons +
  crossbeams + rings, all computed from geometry) replaces the monocoque
  area-density estimate (`k_struct` removed); the per-method skin table
  keeps the print-first (FDM ~321 g) vs 2-ply-carbon trade visible on
  every run.
- **PX4 flight-validation plan before the custom flight controller**
  (ADR-0011): new `px4/` pipeline consumer (downstream of `out/`, like
  `cfd/`) holding a draft custom tailsitter airframe/actuator
  configuration — single EDF + four jet vanes via dynamic control
  allocation, ailerons as the cruise roll effector — plus a Gazebo SITL
  model built from the `out/` handoffs (inertia, vane geometry, motor
  constants). Vane jet-wash aerodynamics in SITL are explicitly
  placeholder pending a custom gz plugin; param names await validation
  against a pinned PX4 release. The custom FC card will be specified
  from flight logs, not estimates.
- CAD: `fuselage_lid`/`fuselage_lower` clamshell split plus assembly-only
  frame display parts (longerons, crossbeams, half-rings, battery rail).

### Changed

- **Design point re-baselined to the semi-monocoque budget** (ADR-0010
  follow-through): `structual_weight_fraction` fitted 0.25 → 0.22 by
  bisection so the structural budget lands at ~110% of the explicit FDM
  member-model estimate after full re-convergence. **MTOW 3.06 →
  2.376 kg** (hover 710 W / 30.3 N, 8.6C peak) — lighter than the
  original 2.5 kg monocoque baseline: the semi-monocoque architecture
  more than pays back the FDM print penalty. All regression pins,
  `cfd/vehicle/Allrun.case` references, and committed `out/` artifacts
  updated. The feasible floor (~0.19) is set by the ADR-0005 guards
  (fixed servo/isolator hardware vs. the shrinking avionics budget).
- ADR-0008's transverse splits (removable nose module, 90° battery hatch)
  are superseded by the clamshell; the two-piece wing + spar and the
  construction-method mechanism remain.
- The ESC cold-plate thermal finding survives at the lighter point
  (~35 W load, plate still over the ESC allocation) — reduced, not
  resolved.

## [0.3.0] — 2026-07-10

Third design snapshot. Adds the first thermal model — the two hover
heat-rejection paths (ESC cold-plate, vented battery bay) sized as
structure — completing the mechanical-design layer (vibration, modularity,
construction, thermal) on top of the 3.06 kg segmented-FDM airframe. The
ESC cold-plate comes out marginal at this power level and is reported as a
standing finding, not tuned away.

### Added

- **Thermal paths as structure** (new pipeline stage `thermal_design`,
  NB7; ADR-0009): first-order sizing of the two hover heat-rejection paths
  as structure — an ESC cold-plate on the inflow-washed inner wall (flat-
  plate forced convection) and a vented battery bay (through-flow). Heat
  loads are derived from the propulsion/battery efficiencies and hover
  power; `config/thermal.yaml` holds only the limits and cooling-airflow
  fractions. Writes `out/thermal.yaml`; two assembly-only CAD parts
  (`esc_cold_plate`, `battery_vents`) excluded from the fused external-aero
  STL. **No mass re-baseline** — the cold-plate is absorbed into the ESC/
  propulsion allocation and no geometry pins move.
- **Finding:** the battery bay vents comfortably (~40x area headroom,
  ~20 C margin), but the ESC cold-plate is **marginal** at the 3.06 kg /
  ~1 kW-hover point — its ~50 W load needs a plate heavier than the ESC
  allocation with only a few C margin. Surfaced honestly (`ok: false` in
  `out/thermal.yaml`, printed in NB7) rather than tuned to a false pass.

### Changed

- Pipeline is now ten notebooks (was nine); `thermal_design` inserts as
  NB7, shifting `vehicle_solid_model` →NB8, `mass_properties` →NB9,
  `wiring_diagram` →NB10.

## [0.2.1] — 2026-07-10

### Fixed

- **Stale CAD part files no longer accumulate.** `export_vehicle` only
  wrote the current per-part STEP/STL and never removed old ones, so
  splitting `fuselage` → `fuselage_nose` + `fuselage_main` (and `wing` →
  `wing_L` + `wing_R`) orphaned the old monolithic `fuselage.*`/`wing.*`
  files in `out/cad/*/parts/`. The Pages 3D viewer globs
  `stl/parts/*.stl`, so the old whole fuselage rendered on top of the two
  split pieces. `export_vehicle` now wipes the per-part directories before
  writing (on-disk parts always equal the current assembly); the 4 orphan
  files are removed. No effect on the mass model — CAD is not an input to
  it.

## [0.2.0] — 2026-07-10

Second design snapshot. Adds the mechanical-design layer the v0.1.0
airframe was hand-waving: vibration isolation, segmented-FDM
construction as the baseline (re-converging the whole design point to
~3.06 kg), and the modularity split lines (removable nose, battery
hatch, two-piece wing) needed to actually build and iterate it.

### Added

- **Segmented-FDM construction as the baseline airframe** (ADR-0008):
  `construction_method` + per-method `k_construction` in
  `config/initial_weight_fraction_estimation.yaml` scale the structural
  fraction inside the mass closure, re-converging the whole design.
  Baseline k=1.1 moves the design point from ~2.5 kg to **~3.06 kg MTOW**
  (~39 N hover thrust, ~1.03 kW hover electrical). NB1 gains a
  side-by-side construction trade study; a new `T_max_N` guard
  (`config/rotor.yaml`) fails the sizing loudly if hover thrust exceeds
  the COTS DS-215-class EDF capability.
- **Modularity split lines** (`config/modularity.yaml`): removable nose
  module (payload access, split just aft of the payload bay), 90-degree
  battery hatch over the battery bay, and a two-piece wing on an 8 mm
  CFRP carry-through spar (matching `wing_lighten --spar-hole`). Joint
  hardware (nose ring, hatch frame, spar tube + root fittings) is carved
  from the structural fraction as named mass; spar tube mass is computed
  from geometry. New `joint_hw`/`spar_hw` layout items, BOM rows, and CAD
  parts (`fuselage_nose`/`fuselage_main`/`battery_hatch`,
  `wing_L`/`wing_R`, assembly-only `spar_tube`) whose unions reproduce
  the OML exactly.
- **Vibration isolation** (new pipeline stage `vibration_isolation`, NB5):
  soft-mounts the FC/IMU cluster and the payload against the EDF 1-per-rev
  imbalance (~211 Hz forcing, derived from rotor RPM). Sizes each as a 1-DOF
  base-excitation isolator — corner frequency, transmissibility, static sag,
  sway space, stiffness, and hardware mass — with a valid-window check
  (above the control bandwidth, below the isolation threshold). Achieves
  ~90% attenuation of the 1/rev at f_n ≈ 58 Hz with a few mm of sway.
  See ADR-0007.
- Isolator hardware is carved from the avionics/structural fractions and the
  sway/rattle space is fed into the fuselage bay stack; the fuselage,
  mass-properties, and CAD notebooks consume `out/vibration.yaml`.
- CAD: soft-mounted FC/IMU tray and payload nose module added to the assembly
  (isolator standoffs + rattle gap), assembly-only — the fused external-aero
  STL is unchanged.

### Changed

- Design point re-baselined: all regression pins, `cfd/vehicle/Allrun.case`
  references (`lRef`, `Aref`, `CofR`), and committed `out/` artifacts
  updated for the 3.06 kg segmented-FDM vehicle.
- Pipeline is now nine notebooks (was eight); `fuselage_design` →NB6,
  `vehicle_solid_model` →NB7, `mass_properties` →NB8, `wiring_diagram` →NB9.
- CFD smoke-run mesh gate now checks mesh *usability* (single region,
  closed boundary, positive cell volumes, solver-safe non-orthogonality,
  skewness ≤ 8) rather than demanding checkMesh's perfect "Mesh OK"
  verdict — the coarsened smoke mesh can trip the skewness heuristic on a
  couple of faces without being unusable.

## [0.1.0] — 2026-07-09

First tagged design snapshot of the electric tail-sitter VTOL UAV
(V-BAT-like, single EDF, jet vanes). Establishes the full one-way design
pipeline — `config/*.yaml` → `src/conceptual_design/` (all physics) →
`notebooks/` (orchestrate) → `out/` (handoffs) → `cfd/` (consumers) — and a
converged conceptual design point.

### Design point

- ≈ 2.5 kg MTOW, COTS 195 mm EDF (Schübeler DS-215 class), ~770 W hover
  electrical, ~9C peak battery discharge.
- 15–20 min mission: 120 s hover + 40 s transitions + 900 s cruise
  (deliberately short-hover — hover is expensive at this disk loading).
- NACA 2412 wing, AR 6, ~1.09 m span; +0.05 MAC cruise static margin.

### Pipeline (8 notebooks, executed in dependency order)

1. `vbat_conceptual_design` — mission sizing, mass closure.
2. `wing_design` — airfoil selection → `out/airfoil.yaml`.
3. `control_vane_design` — jet vanes → `out/control_vanes.yaml`.
4. `aileron_design` — cruise-phase roll backup → `out/aileron.yaml`.
5. `fuselage_design` — packaging, CG, drag → `out/fuselage.yaml`.
6. `vehicle_solid_model` — CadQuery CAD → `out/cad/` (STEP/STL, per-part +
   fused + parametric prop rotor).
7. `mass_properties` — inertia tensor, BOM → `out/mass_properties.yaml`,
   `out/bom.csv`.
8. `wiring_diagram` — generated electrical block diagram →
   `out/wiring_diagram.svg`, `out/electrical.yaml`.

### Control

- **Jet vanes** (4×, X-configuration) provide pitch/yaw/roll in
  hover/transition, sized from hover thrust.
- **Ailerons** (2×) added as the primary roll actuator in wing-borne cruise:
  jet-vane authority scales linearly with thrust and collapses to a thin
  margin in cruise (cruise thrust ≈ L/D⁻¹ of hover thrust), so ailerons —
  driven by wing dynamic pressure — cover roll exactly where the vanes are
  weakest. `ddot_min_deg_s2` (`config/aerodynamics.yaml`) is the single
  authority requirement both notebooks check against.

### Mechanical

- **Adjustable battery-tray CG trim**: rail-mounted battery (±25 mm travel)
  as a bounded, checked CG-trim actuator; `mass_properties` solves the trim
  to hit the target static margin and flags if the requirement exceeds the
  rail travel.
- **Mass-fraction carve-out discipline**: named hardware (vane/aileron
  servos, linkages, battery tray) is carved from the top-down mass-closure
  fraction that documents it (avionics / structural / misc), keeping both
  the original budget and the carved amount on the handoff, with a guard
  that fails loudly rather than silently net down.
- **CAD**: full parametric solid model incl. wing-split ailerons at zero
  deflection and 9g-class aileron servos as lower-surface pods (the wing is
  too thin at the hinge to bury them).

### CFD & geometry

- `cfd/vehicle` OpenFOAM case driven by the exported STL; vehicle CFD models
  the fan as an actuator disk (fused STL excludes blades). Coarse-mesh,
  60-iteration smoke run is the CI ceiling — production CFD runs off-CI.

### CI / tooling

- `ci.yml` — ruff, pytest (3.10/3.12/3.14), ShellCheck on `cfd/**/Allrun*`.
- `design-pipeline.yml` — executes all eight notebooks, runs
  design-regression + geometry tests, uploads `out/`; on main also runs the
  coarse OpenFOAM smoke run and deploys the GitHub Pages design report.
- `release.yml` — pushing a `v*` tag re-runs the pipeline and attaches the
  frozen design snapshot to a GitHub Release.
- Regression pins in `tests/test_design_outputs.py` lock the converged
  design point and cross-check `cfd/vehicle/Allrun.case`; `tests/test_geometry.py`
  guards the exported STL (watertight, mm units, span).

[0.5.2]: https://github.com/onurtuncer/vbat-uav-notebooks/releases/tag/v0.5.2
[0.5.1]: https://github.com/onurtuncer/vbat-uav-notebooks/releases/tag/v0.5.1
[0.5.0]: https://github.com/onurtuncer/vbat-uav-notebooks/releases/tag/v0.5.0
[0.4.5]: https://github.com/onurtuncer/vbat-uav-notebooks/releases/tag/v0.4.5
[0.4.4]: https://github.com/onurtuncer/vbat-uav-notebooks/releases/tag/v0.4.4
[0.4.3]: https://github.com/onurtuncer/vbat-uav-notebooks/releases/tag/v0.4.3
[0.4.2]: https://github.com/onurtuncer/vbat-uav-notebooks/releases/tag/v0.4.2
[0.4.1]: https://github.com/onurtuncer/vbat-uav-notebooks/releases/tag/v0.4.1
[0.4.0]: https://github.com/onurtuncer/vbat-uav-notebooks/releases/tag/v0.4.0
[0.3.0]: https://github.com/onurtuncer/vbat-uav-notebooks/releases/tag/v0.3.0
[0.2.1]: https://github.com/onurtuncer/vbat-uav-notebooks/releases/tag/v0.2.1
[0.2.0]: https://github.com/onurtuncer/vbat-uav-notebooks/releases/tag/v0.2.0
[0.1.0]: https://github.com/onurtuncer/vbat-uav-notebooks/releases/tag/v0.1.0

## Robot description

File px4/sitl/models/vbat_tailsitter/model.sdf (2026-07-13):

<?xml version="1.0"?>
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
<sdf version="1.9">
  <model name="vbat_tailsitter">

    <link name="base_link">
      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
      <inertial>
        <pose>-0.23661 0 0 0 0 0</pose>
        <mass>2.2557</mass>
        <inertia>
          <ixx>0.021369</ixx>
          <iyy>0.040159</iyy>
          <izz>0.051713</izz>
          <ixy>0</ixy><ixz>0</ixz><iyz>0</iyz>
        </inertia>
      </inertial>

      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

      <sensor name="imu_sensor" type="imu">
        <always_on>1</always_on><update_rate>250</update_rate>
      </sensor>
      <sensor name="air_pressure_sensor" type="air_pressure">
        <always_on>1</always_on><update_rate>50</update_rate>
      </sensor>
      <sensor name="magnetometer_sensor" type="magnetometer">
        <always_on>1</always_on><update_rate>100</update_rate>
      </sensor>
      <sensor name="navsat_sensor" type="navsat">
        <always_on>1</always_on><update_rate>30</update_rate>
      </sensor>
      <sensor name="air_speed_sensor" type="air_speed">
        <always_on>1</always_on><update_rate>50</update_rate>
      </sensor>
    </link>

    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
    <link name="rotor_link">
      <pose>-0.4424 0 0 0 0 0</pose>
      <inertial>
        <mass>0.023</mass>
        <inertia><ixx>6e-5</ixx><iyy>3e-5</iyy><izz>3e-5</izz>
          <ixy>0</ixy><ixz>0</ixz><iyz>0</iyz></inertia>
      </inertial>
      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
    </link>
    <joint name="rotor_joint" type="revolute">
      <parent>base_link</parent><child>rotor_link</child>
      <axis><xyz>1 0 0</xyz>
        <limit><lower>-1e16</lower><upper>1e16</upper></limit></axis>
    </joint>

    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
    <link name="vane_t_link">
      <pose>-0.50363 0 0.07105 0 0 0</pose>
      <inertial><mass>0.00343</mass>
        <inertia><ixx>1e-7</ixx><iyy>1e-7</iyy><izz>1e-7</izz>
          <ixy>0</ixy><ixz>0</ixz><iyz>0</iyz></inertia></inertial>
      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
    </link>
    <joint name="vane_t_joint" type="revolute">
      <parent>base_link</parent><child>vane_t_link</child>
      <axis><xyz>0 0 1</xyz>
        <limit><lower>-0.349</lower><upper>0.349</upper></limit></axis>
      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
    </joint>

    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
    <link name="vane_b_link">
      <pose>-0.50363 0 -0.07105 0 0 0</pose>
      <inertial><mass>0.00343</mass>
        <inertia><ixx>1e-7</ixx><iyy>1e-7</iyy><izz>1e-7</izz>
          <ixy>0</ixy><ixz>0</ixz><iyz>0</iyz></inertia></inertial>
      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
    </link>
    <joint name="vane_b_joint" type="revolute">
      <parent>base_link</parent><child>vane_b_link</child>
      <axis><xyz>0 0 1</xyz>
        <limit><lower>-0.349</lower><upper>0.349</upper></limit></axis>
    </joint>

    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
    <link name="vane_l_link">
      <pose>-0.50363 0.07105 0 0 0 0</pose>
      <inertial><mass>0.00343</mass>
        <inertia><ixx>1e-7</ixx><iyy>1e-7</iyy><izz>1e-7</izz>
          <ixy>0</ixy><ixz>0</ixz><iyz>0</iyz></inertia></inertial>
      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
    </link>
    <joint name="vane_l_joint" type="revolute">
      <parent>base_link</parent><child>vane_l_link</child>
      <axis><xyz>0 1 0</xyz>
        <limit><lower>-0.349</lower><upper>0.349</upper></limit></axis>
    </joint>

    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
    <link name="vane_r_link">
      <pose>-0.50363 -0.07105 0 0 0 0</pose>
      <inertial><mass>0.00343</mass>
        <inertia><ixx>1e-7</ixx><iyy>1e-7</iyy><izz>1e-7</izz>
          <ixy>0</ixy><ixz>0</ixz><iyz>0</iyz></inertia></inertial>
      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
    </link>
    <joint name="vane_r_joint" type="revolute">
      <parent>base_link</parent><child>vane_r_link</child>
      <axis><xyz>0 1 0</xyz>
        <limit><lower>-0.349</lower><upper>0.349</upper></limit></axis>
    </joint>

    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
    <link name="aileron_left_link">
      <pose>-0.3555 0.4930 0 0 0 0</pose>
      <inertial><mass>0.005</mass>
        <inertia><ixx>1e-7</ixx><iyy>1e-7</iyy><izz>1e-7</izz>
          <ixy>0</ixy><ixz>0</ixz><iyz>0</iyz></inertia></inertial>
      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
    </link>
    <joint name="aileron_left_joint" type="revolute">
      <parent>base_link</parent><child>aileron_left_link</child>
      <axis><xyz>0 1 0</xyz>
        <limit><lower>-0.349</lower><upper>0.349</upper></limit></axis>
    </joint>

    <link name="aileron_right_link">
      <pose>-0.3555 -0.4930 0 0 0 0</pose>
      <inertial><mass>0.005</mass>
        <inertia><ixx>1e-7</ixx><iyy>1e-7</iyy><izz>1e-7</izz>
          <ixy>0</ixy><ixz>0</ixz><iyz>0</iyz></inertia></inertial>
      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
    </link>
    <joint name="aileron_right_joint" type="revolute">
      <parent>base_link</parent><child>aileron_right_link</child>
      <axis><xyz>0 1 0</xyz>
        <limit><lower>-0.349</lower><upper>0.349</upper></limit></axis>
    </joint>

    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
    <plugin filename="gz-sim-multicopter-motor-model-system" name="gz::sim::systems::MulticopterMotorModel">
      <jointName>rotor_joint</jointName>
      <linkName>rotor_link</linkName>
      <turningDirection>ccw</turningDirection>
      <motorConstant>1.80e-5</motorConstant>
      <momentConstant>0.001</momentConstant> 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
      <maxRotVelocity>1394</maxRotVelocity>
      <timeConstantUp>0.05</timeConstantUp>
      <timeConstantDown>0.08</timeConstantDown>
      <commandSubTopic>command/motor_speed</commandSubTopic>
      <motorNumber>0</motorNumber>
      <motorType>velocity</motorType>
    </plugin>

    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
    <plugin filename="gz-sim-joint-position-controller-system" name="gz::sim::systems::JointPositionController">
      <joint_name>vane_t_joint</joint_name><sub_topic>servo_0</sub_topic>
      <p_gain>2.0</p_gain><i_gain>0.1</i_gain>
    </plugin>
    <plugin filename="gz-sim-joint-position-controller-system" name="gz::sim::systems::JointPositionController">
      <joint_name>vane_b_joint</joint_name><sub_topic>servo_1</sub_topic>
      <p_gain>2.0</p_gain><i_gain>0.1</i_gain>
    </plugin>
    <plugin filename="gz-sim-joint-position-controller-system" name="gz::sim::systems::JointPositionController">
      <joint_name>vane_l_joint</joint_name><sub_topic>servo_2</sub_topic>
      <p_gain>2.0</p_gain><i_gain>0.1</i_gain>
    </plugin>
    <plugin filename="gz-sim-joint-position-controller-system" name="gz::sim::systems::JointPositionController">
      <joint_name>vane_r_joint</joint_name><sub_topic>servo_3</sub_topic>
      <p_gain>2.0</p_gain><i_gain>0.1</i_gain>
    </plugin>
    <plugin filename="gz-sim-joint-position-controller-system" name="gz::sim::systems::JointPositionController">
      <joint_name>aileron_left_joint</joint_name><sub_topic>servo_4</sub_topic>
      <p_gain>2.0</p_gain><i_gain>0.1</i_gain>
    </plugin>
    <plugin filename="gz-sim-joint-position-controller-system" name="gz::sim::systems::JointPositionController">
      <joint_name>aileron_right_joint</joint_name><sub_topic>servo_5</sub_topic>
      <p_gain>2.0</p_gain><i_gain>0.1</i_gain>
    </plugin>

    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
    <plugin filename="gz-sim-lift-drag-system" name="gz::sim::systems::LiftDrag">
      <link_name>base_link</link_name>
      <air_density>1.225</air_density>
      <cla>4.9</cla><cla_stall>-3.85</cla_stall>
      <cda>0.0126</cda><cda_stall>-0.9</cda_stall>
      <alpha_stall>0.22</alpha_stall><a0>0.024</a0>
      <area>0.0917</area>
      <cp>-0.24535 0.26225 0</cp>
      <forward>1 0 0</forward><upward>0 0 1</upward>
      <control_joint_name>aileron_left_joint</control_joint_name>
      <control_joint_rad_to_cl>2.09</control_joint_rad_to_cl>
    </plugin>
    <plugin filename="gz-sim-lift-drag-system" name="gz::sim::systems::LiftDrag">
      <link_name>base_link</link_name>
      <air_density>1.225</air_density>
      <cla>4.9</cla><cla_stall>-3.85</cla_stall>
      <cda>0.0126</cda><cda_stall>-0.9</cda_stall>
      <alpha_stall>0.22</alpha_stall><a0>0.024</a0>
      <area>0.0917</area>
      <cp>-0.24535 -0.26225 0</cp>
      <forward>1 0 0</forward><upward>0 0 1</upward>
      <control_joint_name>aileron_right_joint</control_joint_name>
      <control_joint_rad_to_cl>2.09</control_joint_rad_to_cl>
    </plugin>
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

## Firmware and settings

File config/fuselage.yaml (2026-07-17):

# Fuselage packaging, shape, and structure parameters for the
# V-BAT tail-sitter conceptual design.  Used by fuselage_design.py.
#
# ------------------------------------------------------------------
# AXIS CONVENTION (consistent with the Aetherion 6-DoF library):
#   Body frame:  x forward (out the nose), y right, z down  (FRD)
#   Fuselage stations are measured from the NOSE TIP, positive AFT.
#   Body-frame x of a station:  x_body = -station.
#   The EDF exhaust and the control vanes point in -x (aft).
# ------------------------------------------------------------------
#
# --- Packaging densities -------------------------------------------
# rho_battery_pack : effective pack-level density [kg/m^3]
#                    LiPo cells are ~2000 kg/m^3; wiring, case and
#                    connectors bring the installed pack to ~1500.
#
# rho_payload      : payload density [kg/m^3]
#                    representative EO sensor + mount (~800).
#
# rho_avionics     : avionics density [kg/m^3]
#                    FC + GPS + RX + wiring looms are mostly air (~550).
#
# packing_factor   : usable fraction of a bay's cylindrical volume [-]
#                    accounts for corner losses against the curved
#                    shell, foam, connectors, and access clearances.
#
# part_clearance_m : axial clearance per rigid COTS part in a bay [m].
#                    The post-freeze re-solve (NB14) floors each bay
#                    length at the frozen part's best-orientation axial
#                    length plus this clearance -- a volume-based bay
#                    assumes the contents can be shaped to it, which a
#                    rigid LiPo pack or FC board cannot. 5 mm covers
#                    connector overhang and hand access at one end.
#
# --- Shape ----------------------------------------------------------
# fineness_ratio   : target L_fus / D_fus [-]
#                    Hoerner minimum-drag bodies of revolution lie at
#                    f = 3-6 for fixed volume; 5 keeps the tail-sitter
#                    stubby enough to stand on its duct.
#
# f_nose           : nose length fraction of L_fus [-] (semi-ellipsoid)
# f_tail           : tail-cone length fraction of L_fus [-]
#                    boattail that tapers to the EDF hub diameter and
#                    doubles as the fan centerbody.
#                    (f_mid = 1 - f_nose - f_tail is the cylinder.)
#
# d_hub_margin     : D_fus >= d_hub_margin * (2 * R_hub) [-]
#                    the tail must taper DOWN to the fan hub, so the
#                    max diameter is floored slightly above the hub.
#
# --- Shell structure -------------------------------------------------
# t_shell_m        : PACKAGING wall thickness for the internal bay
#                    radius (r_int = D/2 - t_shell). Since ADR-0010 the
#                    structural skin is sized separately in
#                    config/modularity.yaml (semi-monocoque member
#                    model); this stays as the conservative packaging
#                    allowance so bay geometry is stable across skin
#                    material choices.
#
# rho_shell        : shell laminate density [kg/m^3] (CFRP ~1600)
#
#
# --- Aerodynamics ----------------------------------------------------
# Q_interference   : fuselage interference factor [-] (Raymer: 1.0-1.1
#                    for a mid-wing pod-like body)
#
# --- Stability -------------------------------------------------------
# static_margin    : (x_AC - x_CG) / MAC in cruise [-]
#                    CG ahead of the wing aerodynamic center.  Small
#                    positive value; hover control comes from the jet
#                    vanes, cruise needs only mild static stability.
#
# battery_tray_travel_m : +/- fore-aft rail travel of the battery tray [m]
#                    A sliding tray turns any future payload swap or
#                    mass-estimate refinement into a bounded, checked
#                    adjustment instead of a silent static-margin
#                    regression.  25 mm is a plausible rail length for a
#                    ~90 mm-long battery bay; it is NOT sized to fix a
#                    modeling error (see control-hardware placement below,
#                    which is the actual fix for the previously-observed
#                    NB4/NB6 CG drift).
#
# battery_tray_mass_kg : sliding-rail hardware mass [kg]
#                    two aluminum rails + lock pin + wiring service loop;
#                    carved out of the misc/fasteners budget, not added
#                    on top of MTOW.
#
# --- Control hardware (vane + servo + linkage) mass model -------------
# t_vane_plate_m   : jet-vane CFRP plate thickness [m] (min manufacturable,
#                    NB5) -- combined with `rho_shell` (same CFRP) and the
#                    vane planform area (`out/control_vanes.yaml`) gives
#                    the per-vane mass.
#
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

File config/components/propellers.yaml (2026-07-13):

# Propeller / fan-unit candidates (see selection.yaml for policy/format).
# The rotating unit the motor spins: either a COTS EDF fan cartridge
# (rotor + stator, no motor) or a bare multi-blade propeller run inside
# the airframe's own duct (the duct is airframe structure either way --
# `config/fuselage.yaml` duct geometry, mass in the propulsion fraction).
#
# ADR-0003 froze the 195 mm COTS diameter class; the sizing derives disk
# loading from D_rotor_m (config/rotor.yaml), so a candidate MUST match
# that diameter -- a different-diameter rotor is a different design
# point, not an alternative part. ratings: d_rotor_mm [mm] rotor
# diameter, p_max_w [W] rated max power, n_blades [-]. Cylinder
# primitive: dims_mm = [outer diameter, axial length].
#
# HONEST CATALOG NOTE: the only true COTS EDF unit in the 195 mm class
# is the Schuebeler DS-215-DIA family -- a heavy-lift carbon fan built
# for 10 kW-class jets. Its fan-only mass (EST below; the vendor lists
# only the 3.4 kg fan+motor power unit) dwarfs this vehicle's whole
# propulsion allocation. The two prop entries document the V-BAT-like
# alternative: a low-solidity 3-blade propeller in the airframe duct is
# ~30-50x lighter, but the nearest COTS sizes bracket the frozen
# diameter (7" = 178 mm, 8" = 203 mm) -- adopting one means moving
# D_rotor_m and re-converging, plus revisiting solidity/FoM and the
# empirical RPM law (an ADR-0003 amendment, deliberately NOT smuggled in
# through a parts database).

propellers:
  - id: schuebeler_ds215_dia_hst_fan
    name: Schuebeler DS-215-DIA HST fan (no motor, EST)
    mass_g: 1000.0          # EST fan-only share of the 3.4 kg power unit
    dims_mm: [220.0, 150.0]
    shape: cylinder
    d_rotor_mm: 195.0
    p_max_w: 10000.0
    n_blades: 11
    # no TR source (2026-07): Schuebeler sells factory-direct (DE) only.
  - id: jetfan_130ez
    name: JetFan 130 EZ (130 mm class, EST)
    mass_g: 320.0           # EST -- documents the diameter rejection path
    dims_mm: [140.0, 120.0]
    shape: cylinder
    d_rotor_mm: 130.0
    p_max_w: 8000.0
    n_blades: 10
  - id: ma_3blade_8x6
    name: Master Airscrew 3-blade 8x6 prop (in airframe duct, EST)
    mass_g: 23.0            # EST -- the V-BAT-like light option, 203 mm
    dims_mm: [203.0, 25.0]
    shape: cylinder
    d_rotor_mm: 203.0
    p_max_w: 900.0
    n_blades: 3
  - id: ma_3blade_7x4
    name: Master Airscrew 3-blade 7x4 prop (in airframe duct, EST)
    mass_g: 18.0            # EST -- next COTS size down, 178 mm
    dims_mm: [178.0, 25.0]
    shape: cylinder
    d_rotor_mm: 178.0
    p_max_w: 700.0
    n_blades: 3
    # Master Airscrew has no TR retailer (2026-07) -- import
    # (masterairscrew.com). The TR-procurable prop in the 203 mm class
    # is the 2-blade Gemfan below (same diameter caveat).
  - id: gemfan_apc_8x6
    name: Gemfan APC-style 8x6 glass-nylon prop (in airframe duct, EST)
    mass_g: 15.0            # EST -- TR-stocked 203 mm option, 2-blade
    dims_mm: [203.0, 20.0]
    shape: cylinder
    d_rotor_mm: 203.0
    p_max_w: 900.0          # EST -- same 8-inch sport class as the MA 8x6
    n_blades: 2             # lower solidity than the 3-blade MA --
                            # adopting it re-opens the solidity/FoM
                            # revisit (a further ADR-0003 amendment)
    url: https://www.robotistan.com/gemfan-fiberglass-apc-8x6-drone-propeller-set-2-pc-ccw

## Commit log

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2026-07-04 fuselage design and full-vehicle solid model (CadQuery/OCCT)
    - config/fuselage.yaml + fuselage_design.py: packaging, hub-constrained
    diameter, fineness/drag trade, shell mass, layout/CG, vane arm check
    - notebooks/fuselage_design.ipynb: NB4, writes out/fuselage.yaml handoff
    - cad/: fuselage_body.py (revolved sizing meridian), vehicle_assembly.py
    (wing, duct, struts, centerbody, vanes, legs -> watertight solid),
    wing_profile.py NameError fix + cambered NACA sections
    - notebooks/vehicle_solid_model.ipynb: NB5, exports STEP/STL to out/cad
    - axis convention throughout: Aetherion body FRD, origin at nose tip
    - gitignore .venv/
    [vbat_assembly.step, vbat_fused.step, vbat_fused.stl]
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2026-07-06 Add Tier-1 CI: tests, lint, workflows, docs publishing; fix README
    - README: correct install/run instructions, fill in repo structure,
    fix mission table drift (cruise 1680 s), add CI/Docs badges
    - pyproject.toml: make conceptual_design pip-installable (src layout)
    with dev/cad/notebooks extras and ruff config
    - tests/: 49 pytest tests -- hand-checked reference values, physics
    invariants, and from_yaml round-trips against real config/ files
    - Lint cleanup: fix broken imports in power_to_weight_ratio.py, remove
    shadowed duplicate write_dat_file in airfoil_selection.py, drop
    unused locals/imports across src/
    - CI workflow: ruff + pytest (Python 3.10/3.12/3.14) + shellcheck on
    cfd/ A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
    [fuselage_design.py]
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2026-07-06 Fix stale-state bug in conceptual design notebook
    The rotor parameters were moved to config/rotor.yaml but the notebook
    was never updated to run top-to-bottom: RotorParams was not imported,
    and downstream cells still referenced the D_rotor_m / disk_loading
    names whose literal definitions had been commented out. It only worked
    in the original interactive session where the old names survived in
    kernel state -- caught by the design pipeline's first CI run.
    Import RotorParams and bind D_rotor_m / disk_loading from the YAML so
    all downstream cells work unchanged.
2026-07-06 Fix CFD smoke job: source OpenFOAM env before enabling nounset
    OpenFOAM's bashrc probes unset variables, so 'set -u' before sourcing
    aborts with 'WM_PROJECT_DIR: unbound variable'. Source first, then
    enable nounset. Also don't warn on missing log artifacts when the job
    fails before any logs exist.
2026-07-06 Fix CFD smoke job: install python3 in the OpenFOAM container
    Allrun.case computes the freestream vector with python3, which the
    opencfd/openfoam-default image does not ship. Install it in the job,
    and guard Allrun.case so a missing python3 fails loudly instead of
    slipping through the command substitution and writing a corrupt 0/U.
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2026-07-07 Redesign to COTS 195mm EDF: corrected sizing physics, 15-20 min mission
    Design review outcome (GPT report items 1,2,5 verified as real code
    defects; COTS-only decision):
    Physics (mass_closure):
    - Disk loading is now DERIVED in the loop (DL = MTOW*g/(pi D^2/4));
    it was frozen at the 150 N/m2 initial guess and never updated
    - Hover/climb electrical power now includes the motor+ESC chain
    (FoM covers rotor aero only); was ~232 W, honest value ~766 W
    - Continuous avionics hotel load added to every phase
    - Transition energy budgeted (2x20 s at hover power)
    - Peak C-rate computed and checked against the pack rating
    - Divergence guard: infeasible missions raise instead of returning inf
    No magi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
    [fuselage.yaml, prop_geometry.yaml]
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2026-07-07 Regenerate out/ for the 195mm COTS EDF design point
    Pulled the design-outputs artifact from the passing pipeline run
    (28867308554) and replaced out/ with it: airfoil, fuselage, control
    vanes, mass properties, BOM, and CAD all now reflect the corrected
    sizing physics and 195mm rotor (previously stale from before this
    session's redesign -- local venv is 3.14, CadQuery only runs in CI).
    Also fixes .gitignore: the standard Python "parts/" build-artifact
    pattern was silently swallowing out/cad/{step,stl}/parts/, so the
    new per-part STEP/STL exports (22 parts + standalone prop_rotor)
    were never staged. Added a scoped negation.
    [bom.csv, centerbody.step, centerbody.stl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]
2026-07-07 Add generated electrical wiring diagram (NB7)
    A functional block wiring diagram (battery -> PDB -> ESC -> EDF motor,
    regulated rails, FC hub, RC/telemetry/GNSS/airspeed, companion
    computer + camera, 4x vane servos) rendered as SVG from config/ and
    the converged sizing result -- no hand-maintained drawing file.
    - config/electrical.yaml: the one free electrical variable (battery
    cell count) plus BEC current budgets; everything else (pack voltage/
    capacity, operating current, ESC rating, wire gauge, connector) is
    derived, consistent with the "no magic numbers" rule
    - electrical_diagram.py: fixed, hand-verified collision-free diagram
    topology/layout; only label text is data-driven. Wire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
    [electrical_diagram.py]
2026-07-08 Add adjustable battery-tray CG trim; fix control-hardware mass accounting
    NB6 found the vehicle CG drifting aft of the NB4 estimate because vane,
    servo, and linkage hardware was booked in a mid-body "misc" lump instead
    of at its true aft hinge-line station. Root cause: fuselage_design.py now
    carves servo mass from the avionics fraction and vane+linkage mass from
    the structural fraction (matching config/initial_weight_fraction_estimation.yaml's
    own documented scope for each), and places all of it at the real hinge
    station -- closing nearly the entire static-margin gap (+0.0498 vs +0.05
    target, was -0.0018) without any trim.
    On top of that, add a real rail-mounted battery tray (config/fuselag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
    [bom.csv]
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2026-07-08 Add the 2 aileron servos to the wiring diagram (NB8)
    electrical_diagram.py's fixed SVG layout only ever drew the 4 jet-vane
    servos -- the 2 aileron servos added earlier this session (mass-budget
    and CAD layer) were never wired into NB8. Extends the servo/CC power
    bus and FC PWM signal bus (both already running under the vane-servo
    row) rightward to two new boxes (S-AL/S-AR), sourcing torque from
    out/aileron.yaml instead of a repeated out/control_vanes.yaml value.
    Updates the 4 direct render_wiring_svg() call sites in
    tests/test_electrical_diagram.py for the new required argument, and
    fixes a stale "NB2-NB6" cross-reference in wiring_diagram.ipynb left
    over from the NB4 aileron_design insert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
    [electrical_diagram.py]
2026-07-08 Model the 2 aileron servos in CAD as lower-surface pods (NB6)
    Follow-up to the aileron CAD split: the aileron servos themselves were
    omitted (flagged, not modeled). A 9g servo is ~12 mm thick but this wing
    is only ~6 mm thick at the aileron hinge (0.88c) and ~22 mm at max
    thickness (0.30c), so it cannot be buried inside the aileron the way the
    vane servos bury in the exhaust hub. Modeled instead the way thin-wing
    UAVs actually mount it: a shallow 9g-class fairing/pod on the lower
    (pressure) surface of the fixed wing at the aileron centroid
    (out/aileron.yaml y_arm), forward of the hinge at ~40% chord where the
    section is thickest. The lower-surface seat is read from the same
    airfoil coordinat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
    [aileron_L.step, aileron_R.step, centerbody.step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]
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2026-07-09 Add vibration isolation for FC/IMU and payload (new NB5)
    The single EDF is a high-RPM rotating machine on a stiff CFRP monocoque;
    its 1-per-rev shaft imbalance (~211 Hz, derived from rotor RPM) corrupts
    the IMU and blurs the EO payload. Adds a new pipeline stage
    (vibration_isolation, NB5) that soft-mounts the FC/IMU cluster and the
    payload, sizing each as a 1-DOF base-excitation isolator: corner
    frequency, transmissibility at the forcing frequency, static sag, sway
    space, stiffness and hardware mass, with a valid-window check (above the
    control bandwidth, below the isolation threshold). Achieves ~90%
    attenuation of the 1/rev at f_n ~ 58 Hz with ~0.1 mm static deflection
    and ~0.7 mm sway per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
    [aileron_L.step, aileron_L.stl, aileron_R.step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]
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2026-07-11 Semi-monocoque clamshell fuselage from external design review (ADR-0010)
    Implements Caglar Ucler's structural review: the fuselage becomes a
    longitudinal clamshell -- structural lower half + full-length hinged
    upper lid -- with a rectangular profile around the joint line working as
    the longerons, crossbeam equipment mounts, and 2 half-rings tying the
    lower-centerline battery rail to the frame. The camera/payload bolts to
    the frame, so ADR-0008's transverse splits (removable nose, 90-deg
    battery hatch) are superseded; the two-piece wing + CFRP spar remain.
    An explicit member model (skin + longerons + crossbeams + half-rings,
    every mass computed from geometry) replaces the monocoque area-dens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
    [aileron_L.step, aileron_L.stl, aileron_R.step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]
2026-07-11 Re-baseline the design point to the semi-monocoque budget (ADR-0010)
    Executes the re-baseline ADR-0010 deferred: structual_weight_fraction
    fitted 0.25 -> 0.22 by bisection so the structural budget lands at ~110%
    of the explicit FDM member-model estimate after full re-convergence
    (budget/member = 1.109; the 10% headroom covers landing legs, duct
    struts, and local reinforcements not in the member model).
    MTOW 3.06 -> 2.376 kg (hover 710 W / 30.3 N, 8.6C peak) -- lighter than
    the original 2.5 kg monocoque baseline: the semi-monocoque architecture
    more than pays back the FDM print penalty at the whole-vehicle level.
    The feasible floor (~0.19) is set by the ADR-0005 guards -- below it the
    shrunk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
    [aileron_L.step, aileron_L.stl, aileron_R.step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]
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2026-07-12 Amend ADR-0003: COTS 3-blade prop-in-duct (203 mm) replaces the EDF cartridge
    NB11 put real hardware against ADR-0003 and found the 195 mm COTS EDF
    class has no light implementation -- the only purchasable fan is the
    DS-215 heavy-lift family (fan + lightest motor ~6x / -1069 g over the
    propulsion allocation). The sizing physics always modelled a
    low-solidity prop (sigma 0.077 = a 3-blade 8x6 over the annulus outside
    the 0.4 R hub), so only the procurement assumption changes: the rotor is
    now a COTS 3-blade 8x6 propeller (203 mm, Master Airscrew class) in the
    airframe duct -- what the actual V-BAT flies. Still COTS-only; disk
    loading stays derived.
    D_rotor_m 0.195 -> 0.203, full pipeline re-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
    [bom.csv, edf_motors.yaml, flight_controllers.yaml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]
2026-07-13 Regenerate out/cad at the 203 mm design point; fix rotor-diameter test
    NB8 re-run in a Python 3.12 CadQuery env (2.8.0) so the committed CAD
    matches the ADR-0003-amended 203 mm prop-in-duct point (span 1.049 m);
    NB9 re-run against the fresh CAD. test_config_loading's rotor pin
    updated 0.195 -> 0.203 to the amended decision. 93 tests green in both
    venvs, geometry span check now passes locally.
    [aileron_L.step, aileron_L.stl, aileron_R.step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]
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2026-07-15 Rebuild the prop rotor CAD as the actual COTS 3-blade prop
    The v0.4.1 rotor still had EDF-cartridge proportions at the EDF-era
    station: a 114 mm hub barrel + spinner (hub_length_ratio 0.35,
    spinner_ratio 1.0) placed at the duct CG, burying the hub inside the
    fuselage tailcone, pushing the spinner out through its skin, and
    running the blade roots through the tailcone (still ~83 mm across
    there). With 11 stubby blades this read as an embedded cartridge;
    with 3 blades it was visibly wrong.
    - Hub is now a short adapter collar (hub_length_ratio 0.12, ~24 mm,
    no spinner) sitting ~2 mm proud of the tailcone/centerbody junction
    radius; build_prop_rotor handles spinner_ratio 0 with a flat face.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
    [prop_rotor.step, prop_rotor.stl]
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2026-07-17 Re-solve the estimate-based designs downstream of the COTS freeze (ADR-0012)
    Extend the pipeline to fifteen notebooks. After cots_selection (NB11),
    three new notebooks re-solve NB4-NB6 with the frozen hardware -- as new
    downstream notebooks writing parallel *_cots.yaml handoffs, so the
    design process stays strictly linear (no back-edge; the conceptual
    solutions and the CAD/CFD geometry are untouched):
    - NB12 aileron_design_cots: frozen KST servo (real mass, real stall
    margin: x3.2 vane / x18.5 aileron)
    - NB13 vibration_isolation_cots: frozen Pixhawk 6C mass (FC isolator
    softens 1835 -> 1058 N/m; f_n and sway unchanged by construction)
    - NB14 fuselage_design_cots: as-selected masses, pac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
    [fuselage.yaml, fuselage_design.py]
2026-07-17 Add the Molicel P50B 6S1P Li-ion pack to the battery catalog
    First Li-ion 21700-cell candidate (5 Ah / 108 Wh / 450 g, WREKD-listed
    built pack; bare P50B cells are TR-stocked, so the in-country route is
    a local spot-welded build). It wins the auto-freeze over the Gens Ace
    LiPo, flipping the battery budget line to ~105 g UNDER the sized pack:
    the as-selected all-up drops to 2.264 kg (-38 g vs the closure MTOW)
    and the hull re-solves to ~o107x533 mm. Regression pins, the
    regenerated NB11-NB14 handoffs, and the CLAUDE.md standing findings
    move in the same commit per the pin discipline.
    Watch item: Li-ion nominal is 3.6 V/cell vs the configured 3.7 V/cell
    (config/electrical.yaml) -- revisit if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
    [batteries.yaml]
2026-07-17 Move notebook code into src as thin-orchestration modules (ADR-0013)
    The fifteen notebooks had accumulated ~4,000 lines of Python: a repeated
    path/style prelude, fourteen copies of the config-load + run_sizing_loop
    block, physics that had leaked into NB3 (vane sizing) and NB9 (inertia
    primitives / BOM) against ADR-0002, and duplicated figure/report blocks.
    Notebooks now hold only parameter setting, module calls, and short
    interpretive prints (~1,590 lines). New src modules: notebook.py
    (nb_setup), design_point.py (DesignInputs / solve_design_point -- the
    single sizing call site), control_vane_design.py, mass_properties.py,
    sizing_studies.py, design_summary.py, reports.py, and the plots/
    sub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
    [cots_selection.py, fuselage_design.py, mass_properties.py]
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2026-07-17 Size the wing to the selected airfoil's CL_max (stall-speed fix)
    The 2026-07 external aero review (C. Ucler) verified the wing card and
    found its one inconsistency: the 11.98 m/s stall line was computed from
    config CL_max = 1.4 -- a pre-airfoil-selection "NACA 00xx" placeholder
    -- while everything else on the card came from the selected NACA 2412
    (CL_max_3D = 1.2186). The real wing stalled at ~12.8 m/s, so the
    V_stall <= 12 m/s requirement was silently unmet, and the sizing's
    stall-limited wing-loading boundary was drawn 15% too optimistic.
    Fix: CL_max is now the selected wing's 1.2186 (Raymer 0.9 x Cl_max_2D,
    documented in config/aerodynamics.yaml as tracking the NB2 selection).
    The design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
    [aileron_L.step, aileron_L.stl, aileron_R.step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]
2026-07-18 Re-select the airfoil to NACA 4412; keep V_cruise at 20 m/s (ADR-0015)
    Follow-up to the v0.5.0 stall-consistency fix, which left two open
    items: the 2412 wing flew cruise at CL 0.437 (well below the polar
    optimum, best-range speed ~16.7 m/s) and the section ran with zero
    Cl_max headroom. A trade study on both levers:
    V_cruise sweep (16-22 m/s through the mass closure): in the
    fixed-range framing the closure is nearly V-independent (cruise energy
    = W*R/(L/D*eta) at the configured constant L/D), so changing V_cruise
    ripples the mission, CFD reference velocity, and every handoff for no
    modelled gain. Rejected.
    Airfoil trade (0012/2412/4412/2415 at the current design point; MTOW
    invariant -- t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
    [aileron_L.step, aileron_L.stl, aileron_R.step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]
2026-07-19 Fold pack internal resistance into the closure consistently (ADR-0014 amendment)
    eta_bat 0.97 -> 0.916: the mission-averaged I^2*R efficiency of the
    nominal 90 mOhm pack, iterated to the closure fixed point (0.97 implied
    an unrealistic ~23 mOhm pack). The battery-bay vent load now uses the
    same I^2*R law as the ADR-0014 mission transient. Honest accounting
    costs +215 g: MTOW 2.303 -> 2.518 kg (hover 743 W, 8.1C; S 0.1883 m^2,
    b 1.063 m).
    Standing findings move with the point: nominal-pack transient worsens
    to ~65 C vs the 60 C limit; ESC cold-plate ~37 W (still marginal);
    margined ESC requirement ~54 A (APD 80F3[x] still clears; the Molicel
    c_rate_cont raised to the cell's 60 A datasheet ra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
    [aileron_L.step, aileron_L.stl, aileron_R.step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]
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2026-07-19 Land the ADR-0014 amendment design point and vane control surfaces
    Folds the two [Unreleased] workstreams onto the handoff branch so the
    design-regression pins are consistent again:
    - ADR-0014 amendment: eta_bat 0.97 -> 0.916 (mission-averaged I2R
    efficiency of the nominal 90 mOhm pack, iterated to the closure
    fixed point) and the vent load on the same I2R law. MTOW 2.303 ->
    2.518 kg (hover 743 W, 8.1C peak; S 0.1883 m^2, b 1.063 m). Standing
    findings move with it (transient ~65 C vs 60 C limit, cold plate
    ~37 W, ESC req ~54 A, battery -203 g, as-selected all-up 2.336 kg);
    the ADR-0012 structure-over-budget finding is resolved. Pins,
    Allrun.case, CLAUDE.md, and all out/ artifa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
    [aileron_L.step, aileron_R.step, battery_rail.step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]
2026-07-19 Mint handoff schema 1.1.0: explicit control-surface lattice binding
    From the Aeolion-side integration review: the 1.0.0 document mixed the
    wing aileron (eta on the semispan) and the four cruciform duct-jet
    vanes (eta on the duct-exit radius) in one control_surfaces array with
    no surface association -- binding them to a lattice was ambiguous.
    control_surfaces entries now carry an optional `surface` field:
    wing -- eta is the semispan fraction of the planform
    duct_jet -- all-moving plate in the jet, eta is the duct-exit radius
    fraction, never bound to a lifting-surface lattice
    The field is optional so 1.0.0 documents remain valid (bind by name
    when absent: aileron/rudder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
    [aileron_L.step, aileron_R.step, battery_rail.step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]
2026-07-19 Mint handoff schema 1.2.0: optional fuselage body block
    The contract carried only the lifting/propulsion geometry; the
    fuselage existed solely in the STEP artifacts, off the derivative
    path. A wing-only lattice cannot see the body's Munk moment (trim,
    neutral point) and the duct-jet path needs the centerbody/tailcone
    context upstream of the vanes.
    New optional top-level `body` block: the fuselage as a body of
    revolution -- {x, radius} stations sampled from the SAME 3-segment
    meridian the CAD revolve is built from (fuselage_design.
    fuselage_radius: elliptical nose, cylinder, tail cone to the hub
    radius), cosine-spaced nose -> tail at the fixed n_body_stations
    count (config/aeolion.yaml, 25),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
    [aileron_L.step, aileron_R.step, battery_rail.step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]
2026-07-20 Mint handoff schema 1.3.0: add missing propulsion_bemt.n_blades
    Caught in review: the schema had disk_radius, reference_rpm, and
    blade_stations, but no blade count. BEMT solidity and thrust are
    per-blade quantities scaled by n_blades -- blade_stations alone
    describes one blade's chord/twist law, not the rotor. A load-bearing
    gap, not an optional refinement.
    n_blades sourced from the same prop_geometry.PropGeometry the blade
    stations already sample (config/prop_geometry.yaml, 3 for the COTS
    prop class). schema_version enum grows to add "1.3.0"; 1.0.0-1.2.0
    documents remain valid. Exporter stamps 1.3.0; design_id moves, as
    designed. ADR-0016 + changelog updated; NB8 re-executed; 125 tests
    gre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
    [aileron_L.step, aileron_R.step, battery_rail.step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]
2026-07-20 Mint handoff schema 1.4.0: control-surface deflection range for CFD sweeps
    Every control_surfaces entry now carries deflection_limits_deg
    (min/max, the symmetric mechanical range about hinge_axis, right-hand
    rule, from +-delta_max_deg in out/aileron.yaml / out/control_vanes.yaml)
    so a CFD/VLM deflection sweep stays within the range the physical
    actuator/plate can actually reach. Vane entries additionally carry
    deflection_soft_limit_deg (the flat-plate stall onset, delta_stall_deg)
    -- informational, not a hard bound, since sweeping past stall onset is
    a legitimate off-design query.
    New guard: ail/vanes delta_max_deg must be positive (same pattern as
    the other build_aeolion_geometry guards).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
    [aileron_L.step, aileron_R.step, battery_rail.step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]
2026-07-21 Mint handoff schema 1.5.0: wing/body placement anchor
    Fixes an Aeolion solver-side bug report: the planform and the body
    profile each implicitly started at the reference-frame origin with no
    stated relationship, so a consumer with no other convention to fall
    back on placed the wing root at the fuselage nose -- 22 of 384 wing
    control points landed inside the body of revolution, a boundary
    condition with no physical meaning.
    New planform.placement.root_leading_edge {x, y, z}, same body-frame
    convention as `body` (x = -station, 0 at the nose tip). Anchor is
    [-x_wing_LE_m, 0, 0]: the wing chord datum sits on the fuselage
    centerline by construction (a through-fuselage wing on the ADR-0008
    carry-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
    [aileron_L.step, aileron_R.step, battery_rail.step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]
2026-07-21 Mint handoff schema 1.6.0: moment reference point for Cm
    Fixes an Aeolion solver report: the contract had no CG/moment
    reference, so any Cm/Cl/Cn from a VLM/BEMT sweep of this geometry was
    implicitly referenced to the coordinate-system origin -- not
    physically meaningful for a body whose CG sits well aft of the nose.
    New top-level moment_reference_point {x, y, z}, SAME body-frame
    convention as `body`/`planform.placement` (x = -station, 0 at the
    nose tip) and, deliberately, the SAME source cfd/vehicle/Allrun.case's
    CofR already uses (out/fuselage.yaml x_CG_m) -- so VLM/BEMT moments
    computed from this contract stay directly comparable to the project's
    CFD force/moment coefficients rather than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
    [aileron_L.step, aileron_R.step, battery_rail.step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]
2026-07-21 Adopt Clark Y as the propeller blade section; add rotation sense (ADR-0017)
    Two related gaps caught during Aeolion BEMT integration:
    1. The CAD rotor blade lofted an ad-hoc parametric taper
    (camber_M/camber_P/tc_root/tc_tip, "NACA 4-digit, thickness
    tapering") with no published 2D polar data behind it. Replaced
    with Clark Y -- the classical propeller section with the deepest
    track record in BEMT/momentum-theory validation literature, chosen
    over Selig S1223 (extreme camber, optimized for one hover design
    point -- a poor fit for a rotor that spans hover through cruise as
    the same blade) and Eppler E387 (a general low-Re WING section,
    more wing-proven than propeller-pr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
    [aileron_L.step, aileron_R.step, battery_rail.step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]
2026-07-21 Split the Aeolion handoff into its own notebook (ADR-0018)
    The ADR-0016 handoff had grown enough (six schema revisions, ADR-0017's
    blade-section decision, a numerically-derived rotation sense) that it
    no longer read as an afterthought at the tail of vehicle_solid_model
    (NB8) -- and on inspection it never actually needed anything CAD gives
    it: every build_aeolion_geometry input comes from config/ or an
    upstream out/*.yaml handoff, never the CAD solid or its STEP/STL.
    aeolion_handoff.py and prop_geometry.py are already, deliberately,
    CadQuery-free.
    New NB9 `aeolion_handoff`, thin-notebook style (design_point.
    solve_design_point / load_handoff, not NB8's inline sizing block),
    inserted right af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
    [aileron_L.step, aileron_R.step, battery_rail.step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]
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
